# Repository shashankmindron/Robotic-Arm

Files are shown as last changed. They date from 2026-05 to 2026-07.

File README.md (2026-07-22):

# Robotic Arm — Mechanical Design → Embedded Firmware → ROS 2 Motion Planning







A self-designed 2-DOF five-bar linkage robotic arm, built as a full-stack robotics project: CAD → 3D-printed/machined hardware → custom embedded firmware → a ROS 2 + MoveIt 2 motion planning and control stack, connected over a hand-rolled binary serial protocol.

This isn't a simulation-only or tutorial-following project — every layer (mechanical, firmware, kinematics, planning, and the ros2_control integration) is custom-built for this specific arm's geometry and hardware.

## Highlights

- **Mechanical design:** Custom five-bar (parallel-linkage) arm designed in CAD from scratch — full STEP/STL source in [`cad/`](./cad)
- **Closed-form kinematics from first principles:** Derived and implemented forward and inverse kinematics for a five-bar linkage, including all 4 valid IK branches and transmission-angle singularity detection (`five_bar_kinematics.py`)
- **Motion planning:** An A* planner that searches over `(x, y, kinematic-branch)` states, costing branch switches and validating every candidate against MoveIt 2's live collision-checking service (`astar_planner.py`)
- **MoveIt 2 integration:** Full MoveIt Setup Assistant configuration (SRDF, kinematics, joint limits, RViz) driving real-time collision validation
- **`ros2_control` hardware plugin written in C++:** A `SystemInterface` plugin with a ring-buffer serial parser, custom packet framing, and lifecycle management (`arm_hardware_interface.cpp`)
- **Embedded firmware:** ESP32/Arduino firmware driving two closed-loop stepper drivers via `FastAccelStepper`, with fault/alarm handling and 50 Hz telemetry feedback
- **Designed a binary wire protocol** for low-latency, low-overhead host↔microcontroller communication (see [Serial Protocol](#serial-protocol))
- ~1,900 lines of original Python/C++/firmware code across planning, control, and embedded layers

## System Architecture

```
                     /target_pose (x, y)
                             │
                             ▼
                 ┌──────────────────────┐        /check_state_validity
                 │   robot_arm_ik       │◄───────────────────────────────┐
                 │   (ik_node.py)       │                                │
                 └─────────┬────────────┘                        ┌───────────────┐
                           │ plan request                        │    MoveIt 2   │
                           ▼                                     │  (collision   │
                 ┌──────────────────────┐                        │   checking)   │
                 │   A* Planner         │────────────────────────►               │
                 │ (branch + collision  │                        └───────────────┘
                 │  aware search)       │
                 └─────────┬────────────┘
                           │ synchronized motion frames (~100 Hz)
                           ▼
                 ┌─────────────────────┐   18-byte binary packets   ┌─────────────┐
                 │  Serial Link (UART  │───────────────────────────►│   ESP32     │
                 │  115200 baud        │◄───────────────────────────│  Firmware   │
                 └─────────────────────┘   11-byte telemetry (50Hz) └──────┬──────┘
                                                                           │
                                                                  FastAccelStepper
                                                                           │
                                                                 ┌─────────▼─────────┐
                                                                 │ 2× Stepper Motors │
                                                                 │ (T60 drivers)     │
                                                                 └───────────────────┘
```

## Repository Structure

```
Robotic-Arm/
├── cad/                          # Original CAD (STEP + STL) for the five-bar arm
├── firmware/esp_microros/        # ESP32 firmware — stepper control + binary serial protocol
├── src/
│   ├── arm_bringup/              # Top-level launch file for the full stack
│   ├── arm_commander/            # High-level command API (in progress)
│   ├── arm_hardware_interface/   # ros2_control C++ plugin + URDF/xacro + visual meshes
│   ├── arm_moveit_config/        # MoveIt 2 config (SRDF, kinematics, RViz, demo launch)
│   └── robot_arm_ik/             # Kinematics, planning, and the main control node
└── .gitignore
```

## How It Works

1. A target end-effector position is published on **`/target_pose`**.
2. The **A\* planner** searches the workspace, switching between the linkage's four kinematic branches when needed, validating each state live against MoveIt's collision service.
3. The resulting path is interpolated at ~100 Hz into per-tick motor angle/speed commands.
4. Commands are packed into compact binary frames and streamed to the ESP32 over serial.
5. The **firmware** drives both steppers via `FastAccelStepper`, monitors driver fault lines, and reports back live motor position at 50 Hz.
6. Live joint states are republished for RViz visualization and closed-loop tracking.

The same wire protocol is also exposed as a standard **`ros2_control`** hardware interface, so the arm can be driven through ROS 2's conventional controller pipeline (`position_controller` / `joint_state_broadcaster`) as well as the direct planning path.

## Tech Stack

| Layer | Tools |
|---|---|
| Mechanical | CAD (STEP/STL export) |
| Firmware | C++ (Arduino/ESP32), FastAccelStepper |
| Low-level control | C++, `ros2_control`, `pluginlib`, POSIX serial (termios) |
| Kinematics & Planning | Python, NumPy, custom A* search |
| Motion Planning Framework | ROS 2, MoveIt 2 |
| Communication | Custom binary serial protocol over UART |

## Serial Protocol

Designed for minimal latency and overhead between the host and the ESP32:

| Direction | Size | Layout |
|---|---|---|
| Host → ESP32 (command) | 18 bytes | `0xAA` \| `motor_a_rad` (f32) \| `motor_b_rad` (f32) \| `motor_a_hz` (f32) \| `motor_b_hz` (f32) \| `0xBB` |
| ESP32 → Host (telemetry) | 11 bytes | `0xCC` \| `status` (u8) \| `current_a_rad` (f32) \| `current_b_rad` (f32) \| `0xDD` |

## Getting Started

```bash
# 1. Build the ROS 2 workspace
colcon build
source install/setup.bash

# 2. Flash firmware/esp_microros/esp_microros.ino to the ESP32
#    (Arduino IDE or PlatformIO, with FastAccelStepper installed)

# 3. Launch the full stack
ros2 launch arm_bringup arm.launch.py

# 4. Send a target position
ros2 topic pub /target_pose geometry_msgs/msg/Point "{x: 0.0, y: 400.0}" --once

# 5. Visualize in RViz (optional)
ros2 launch arm_moveit_config demo.launch.py
```

## Roadmap

- [ ] High-level command API in `arm_commander`
- [ ] Trajectory blending for smoother multi-point paths
- [ ] Camera-based perception for closed-loop pick-and-place

## About Me

Built by **Shashank Vijavargia** — mechanical design, embedded firmware, and ROS 2 software all done end-to-end for this project.

*Add your LinkedIn / portfolio site / email here so recruiters can reach you.*

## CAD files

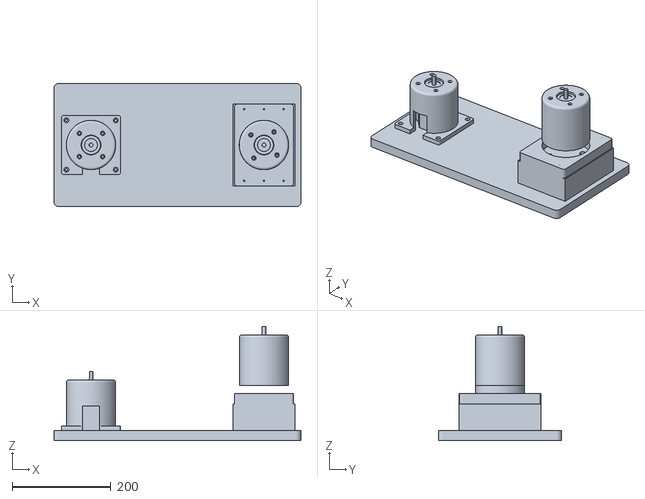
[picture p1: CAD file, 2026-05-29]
src/arm_hardware_interface/meshes/visual/base_assembly.stl
500.0 x 250.0 x 231.2

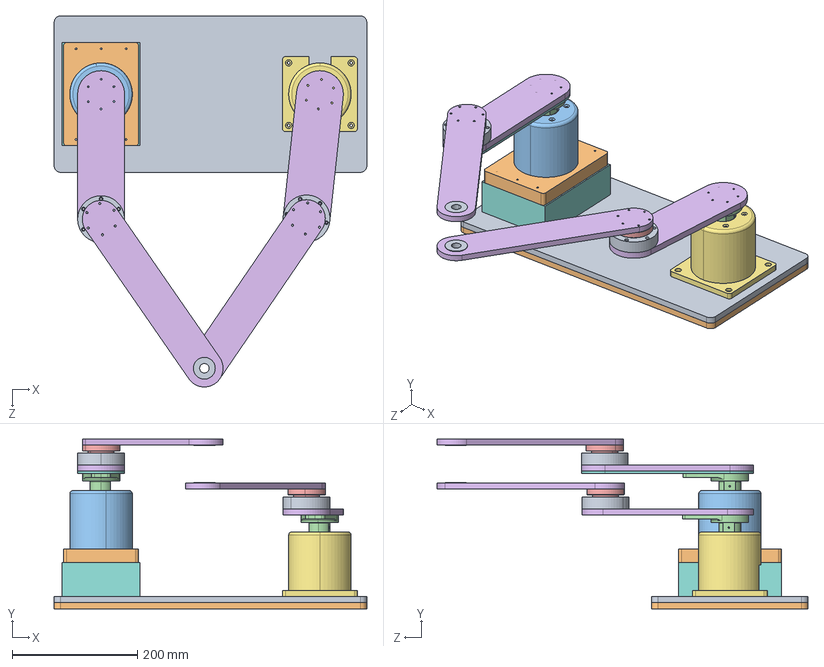
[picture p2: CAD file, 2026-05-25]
cad/scara arm.STEP
500.0 x 271.4 x 593.4 mm
base plate01
57am23ed1 x 2
FIRST MOTOR BASE SUPPORT
Linkage01 x 2
small 01 motor mounting plate
Base plate 02
bearing bush and support x 2
motor mounting base 01
motor mounting base 02
tappered roller bearing 32907 x 2
bush for 2nd bearing x 2
arm _2_1 x 2
Bearing small
Linkage01_01
35x15 bearing x 2

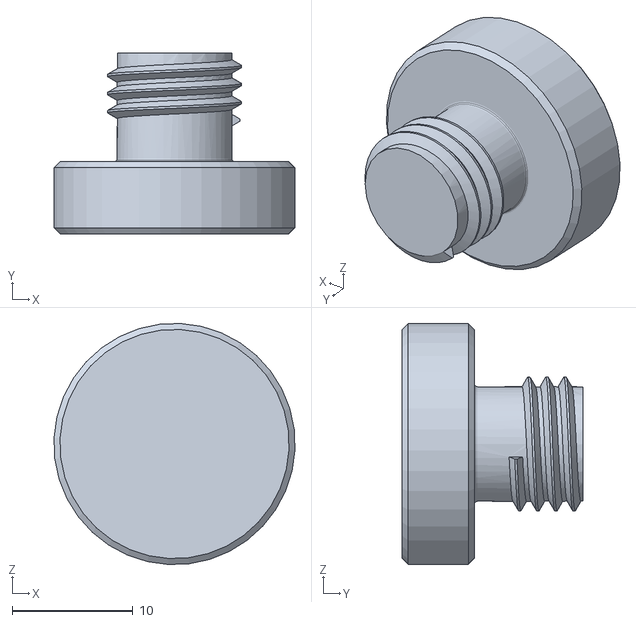
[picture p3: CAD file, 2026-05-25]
cad/stl/scara arm - threaded shaft bush-1.STL
20.0 x 15.0 x 20.0

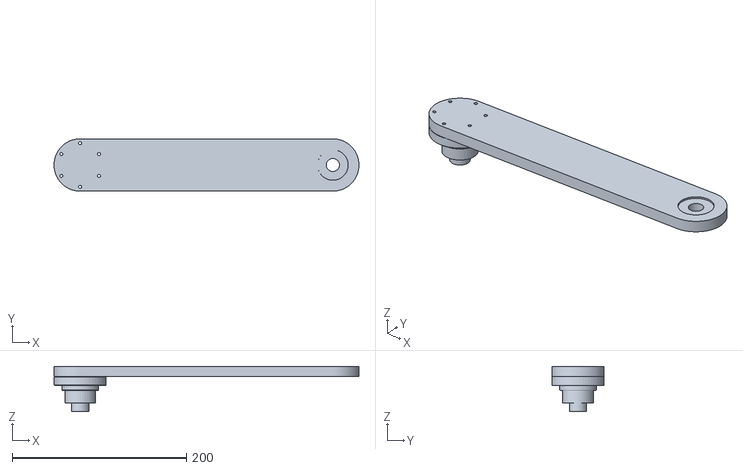
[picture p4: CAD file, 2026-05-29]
src/arm_hardware_interface/meshes/visual/distal_right.stl
350.0 x 60.0 x 51.7

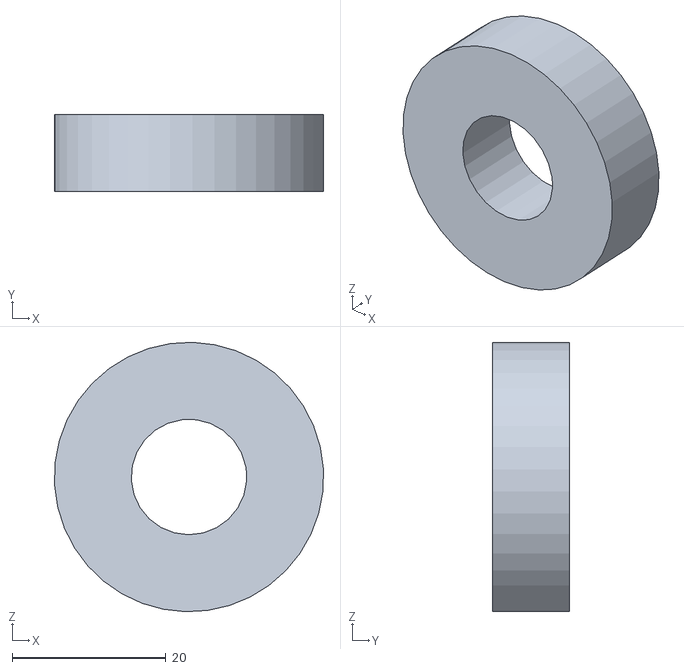
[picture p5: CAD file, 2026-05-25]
cad/stl/scara arm - 35x15 bearing-2.STL
34.9 x 10.0 x 35.0

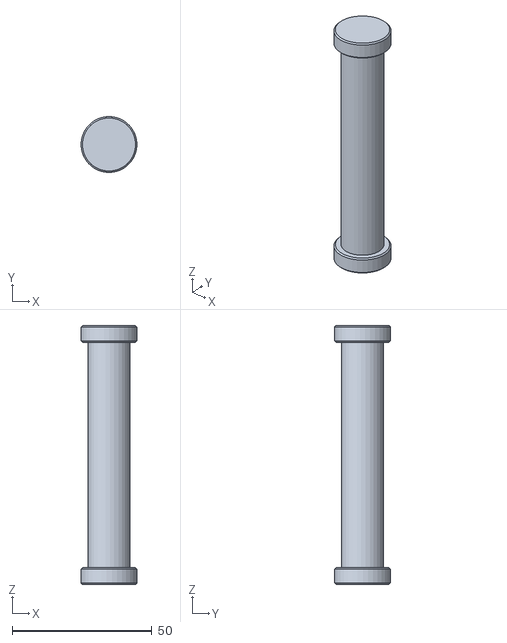
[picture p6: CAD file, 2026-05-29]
src/arm_hardware_interface/meshes/visual/end_effector.stl
20.0 x 20.0 x 92.6

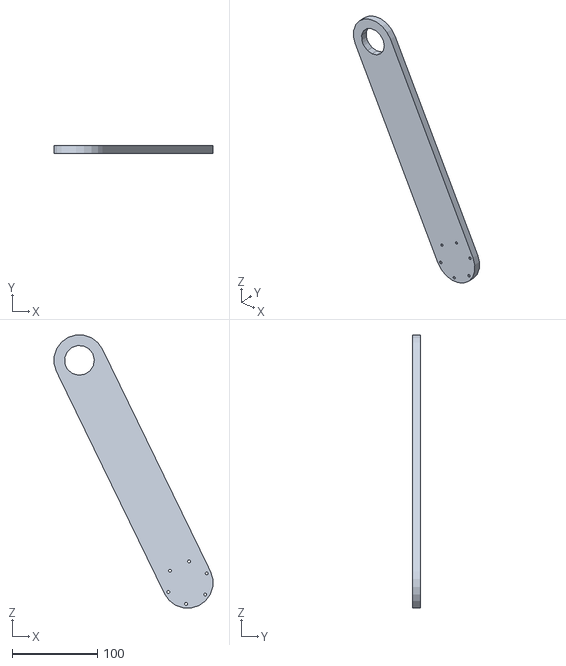
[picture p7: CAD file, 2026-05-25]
cad/stl/scara arm - arm _2_1-3.STL
186.3 x 9.20 x 320.2

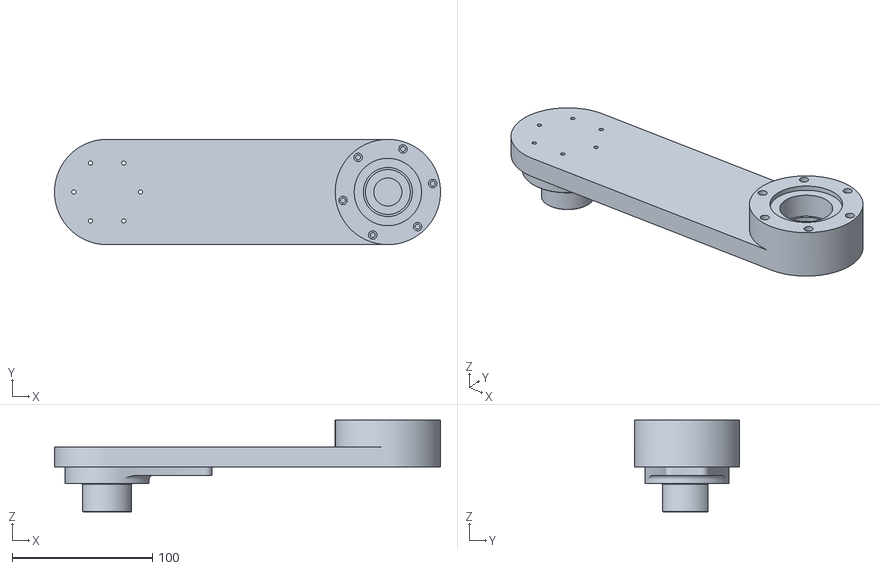
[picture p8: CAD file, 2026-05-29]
src/arm_hardware_interface/meshes/visual/proximal_left.stl
275.0 x 75.0 x 65.2

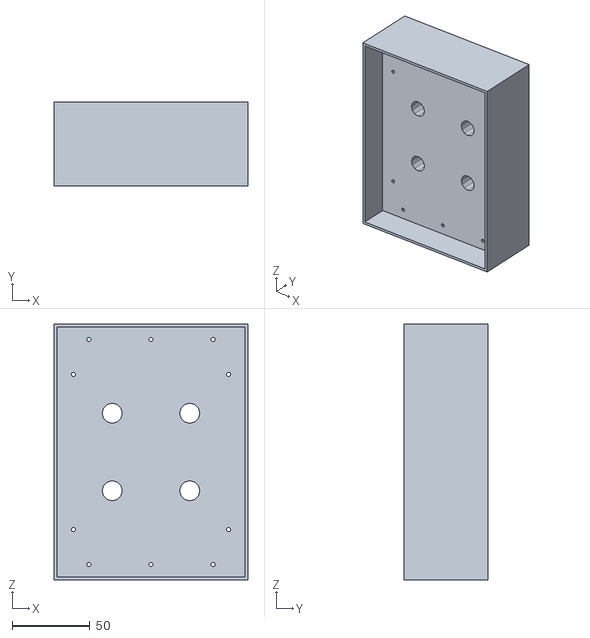
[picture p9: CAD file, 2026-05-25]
cad/stl/scara arm - Base plate 02-1.STL
125.0 x 54.0 x 165.0

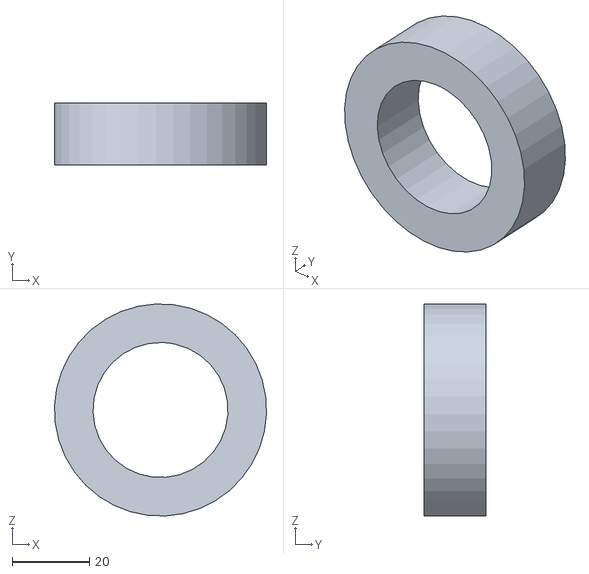
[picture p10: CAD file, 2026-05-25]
cad/stl/scara arm - tappered roller bearing 32907-1.STL
55.0 x 16.0 x 54.9

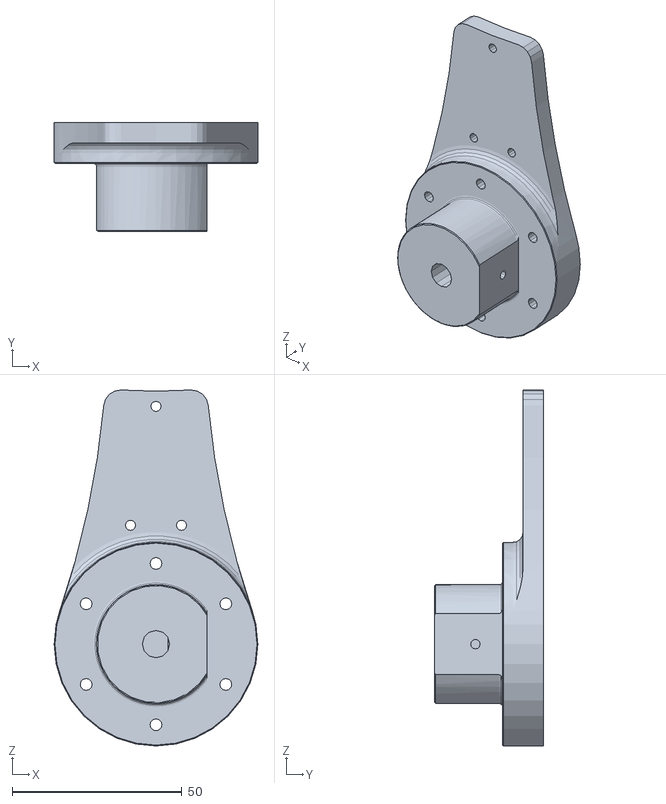
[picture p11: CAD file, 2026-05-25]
cad/stl/scara arm - 123-1.STL
60.0 x 32.0 x 104.8

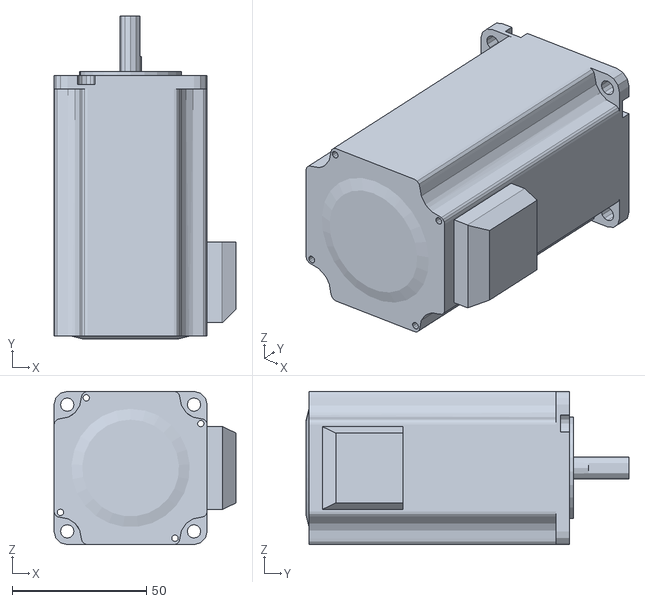
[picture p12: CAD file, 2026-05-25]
cad/stl/scara arm - 57am23ed1-2.STL
67.7 x 120.0 x 57.0

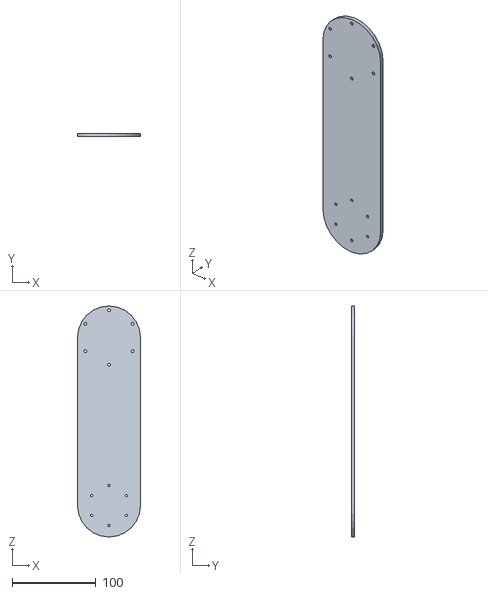
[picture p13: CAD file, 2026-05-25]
cad/stl/scara arm - Linkage01_01-1.STL
75.0 x 4.00 x 275.0

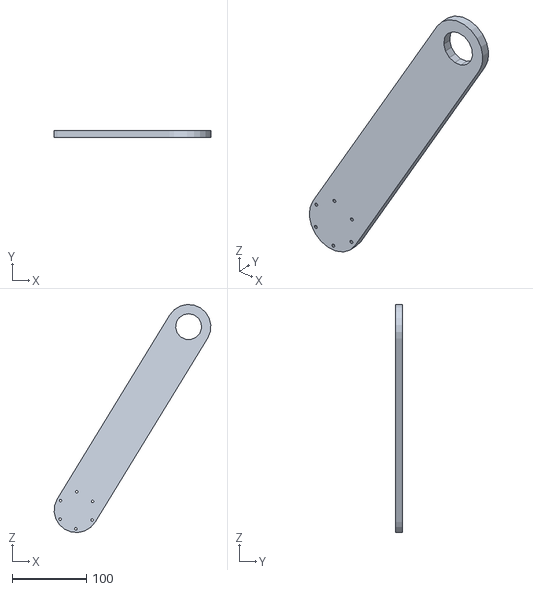
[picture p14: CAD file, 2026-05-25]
cad/stl/scara arm - arm _2_1-2.STL
211.1 x 9.20 x 307.2

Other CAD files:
cad/stl/scara arm - Linkage01-2.STL
cad/stl/scara arm - motor mounting base 02-2.STL
cad/stl/scara arm - 123-2.STL
cad/stl/scara arm - 35x15 bearing-1.STL
cad/stl/scara arm - 57am23ed1-1.STL
cad/stl/scara arm - Bearing small-3.STL
cad/stl/scara arm - FIRST MOTOR BASE SUPPORT-1.STL
cad/stl/scara arm - Linkage01-1.STL
cad/stl/scara arm - Part5-1.STL
cad/stl/scara arm - base plate01-1.STL
cad/stl/scara arm - bearing bush and support-1.STL
cad/stl/scara arm - bearing bush and support-2.STL
cad/stl/scara arm - bush for 2nd bearing-2.STL
cad/stl/scara arm - bush for 2nd bearing-3.STL
cad/stl/scara arm - motor mounting base 01-2.STL
cad/stl/scara arm - small 01 motor mounting plate-1.STL
cad/stl/scara arm - tappered roller bearing 32907-2.STL
cad/stl/scara arm - threaded shaft bush-2.STL

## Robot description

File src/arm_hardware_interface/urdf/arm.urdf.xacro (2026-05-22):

<?xml version="1.0"?>
<robot name="arm" xmlns:xacro="http://www.ros.org/wiki/xacro">
  <!-- Ground link -->
  <link name="base_link" />

  <!-- Motor joints (driven) -->
  <joint name="joint_a" type="revolute">
    <parent link="base_link"/>
    <child link="link_a"/>
    <origin xyz="0 0 0" rpy="0 0 0"/>
    <axis xyz="0 0 1"/>
    <limit lower="-3.14" upper="3.14" effort="1" velocity="1"/>
  </joint>

  <joint name="joint_b" type="revolute">
    <parent link="base_link"/>
    <child link="link_b"/>
    <origin xyz="0.1 0 0" rpy="0 0 0"/>  <!-- separation distance d -->
    <axis xyz="0 0 1"/>
    <limit lower="-3.14" upper="3.14" effort="1" velocity="1"/>
  </joint>

  <link name="link_a">
    <inertial>
      <mass value="0.1"/>
      <origin xyz="0 0 0"/>
      <inertia ixx="0.001" ixy="0" ixz="0" iyy="0.001" iyz="0" izz="0.001"/>
    </inertial>
  </link>
  <link name="link_b">
    <inertial>
      <mass value="0.1"/>
      <origin xyz="0 0 0"/>
      <inertia ixx="0.001" ixy="0" ixz="0" iyy="0.001" iyz="0" izz="0.001"/>
    </inertial>
  </link>

  <!-- Passive links (for completeness) -->

  <!-- ros2_control tag (keep your existing hardware plugin) -->
  <ros2_control name="ArmControl" type="system">
    <hardware>
      <plugin>arm_hardware_interface::ArmHardwareInterface</plugin>
      <param name="serial_port">/dev/ttyUSB0</param>
    </hardware>
    <joint name="joint_a">
      <command_interface name="position"/>
      <state_interface name="position"/>
    </joint>
    <joint name="joint_b">
      <command_interface name="position"/>
      <state_interface name="position"/>
    </joint>
  </ros2_control>
</robot>

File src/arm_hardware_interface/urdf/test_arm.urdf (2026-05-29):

<?xml version="1.0" ?>
<!-- =================================================================================== -->
<!-- |    This document was autogenerated by xacro from arm.urdf.xacro                 | -->
<!-- |    EDITING THIS FILE BY HAND IS NOT RECOMMENDED                                 | -->
<!-- =================================================================================== -->
<robot name="arm">
  <link name="base_link">
    <visual>
      <origin rpy="0 0 0" xyz="0 0 0"/>
      <geometry>
        <mesh filename="package://arm_hardware_interface/meshes/visual/base_assembly.stl" scale="0.001 0.001 0.001"/>
      </geometry>
      <material name="dark_grey">
        <color rgba="0.3 0.3 0.3 1.0"/>
      </material>
    </visual>
    <collision>
      <origin rpy="0 0 0" xyz="0 0 0"/>
      <geometry>
        <mesh filename="package://arm_hardware_interface/meshes/visual/base_assembly.stl" scale="0.001 0.001 0.001"/>
      </geometry>
    </collision>
    <inertial>
      <mass value="1.0"/>
      <origin xyz="0 0 0"/>
      <inertia ixx="0.01" ixy="0" ixz="0" iyy="0.01" iyz="0" izz="0.01"/>
    </inertial>
  </link>
  <joint name="joint_a" type="revolute">
    <parent link="base_link"/>
    <child link="link_a"/>
    <origin rpy="0 0 0" xyz="-0.175 0 0.12915"/>
    <axis xyz="0 0 1"/>
    <limit effort="10.0" lower="-3.14" upper="3.14" velocity="3.0"/>
  </joint>
  <link name="link_a">
    <visual>
      <origin rpy="0 0 0" xyz="0 0 0"/>
      <geometry>
        <mesh filename="package://arm_hardware_interface/meshes/visual/proximal_left.stl" scale="0.001 0.001 0.001"/>
      </geometry>
      <material name="orange">
        <color rgba="0.9 0.45 0.0 1.0"/>
      </material>
    </visual>
    <collision>
      <origin rpy="0 0 0" xyz="0 0 0"/>
      <geometry>
        <mesh filename="package://arm_hardware_interface/meshes/visual/proximal_left.stl" scale="0.001 0.001 0.001"/>
      </geometry>
    </collision>
    <inertial>
      <mass value="0.1"/>
      <origin xyz="0.100 0 0"/>
      <inertia ixx="0.001" ixy="0" ixz="0" iyy="0.001" iyz="0" izz="0.001"/>
    </inertial>
  </link>
  <joint name="joint_b" type="revolute">
    <parent link="base_link"/>
    <child link="link_b"/>
    <origin rpy="0 0 0" xyz="0.175 0 0.22035"/>
    <axis xyz="0 0 1"/>
    <limit effort="10.0" lower="-3.14" upper="3.14" velocity="3.0"/>
  </joint>
  <link name="link_b">
    <visual>
      <origin rpy="0 0 0" xyz="0 0 0"/>
      <geometry>
        <mesh filename="package://arm_hardware_interface/meshes/visual/proximal_right.stl" scale="0.001 0.001 0.001"/>
      </geometry>
      <material name="orange"/>
    </visual>
    <collision>
      <origin rpy="0 0 0" xyz="0 0 0"/>
      <geometry>
        <mesh filename="package://arm_hardware_interface/meshes/visual/proximal_right.stl" scale="0.001 0.001 0.001"/>
      </geometry>
    </collision>
    <inertial>
      <mass value="0.1"/>
      <origin xyz="0.100 0 0"/>
      <inertia ixx="0.001" ixy="0" ixz="0" iyy="0.001" iyz="0" izz="0.001"/>
    </inertial>
  </link>
  <joint name="joint_distal_a" type="continuous">
    <parent link="link_a"/>
    <child link="link_distal_a"/>
    <origin rpy="0 0 0" xyz="0.200 0 0.044"/>
    <axis xyz="0 0 1"/>
  </joint>
  <link name="link_distal_a">
    <visual>
      <origin rpy="0 0 0" xyz="0 0 0"/>
      <geometry>
        <mesh filename="package://arm_hardware_interface/meshes/visual/distal_left.stl" scale="0.001 0.001 0.001"/>
      </geometry>
      <material name="blue">
        <color rgba="0.1 0.4 0.8 1.0"/>
      </material>
    </visual>
    <collision>
      <origin rpy="0 0 0" xyz="0 0 0"/>
      <geometry>
        <mesh filename="package://arm_hardware_interface/meshes/visual/distal_left.stl" scale="0.001 0.001 0.001"/>
      </geometry>
    </collision>
    <inertial>
      <mass value="0.1"/>
      <origin xyz="0.1446 0 0"/>
      <inertia ixx="0.001" ixy="0" ixz="0" iyy="0.001" iyz="0" izz="0.001"/>
    </inertial>
  </link>
  <joint name="joint_distal_b" type="continuous">
    <parent link="link_b"/>
    <child link="link_distal_b"/>
    <origin rpy="0 0 0" xyz="0.200 0 0.044"/>
    <axis xyz="0 0 1"/>
  </joint>
  <link name="link_distal_b">
    <visual>
      <origin rpy="0 0 0" xyz="0 0 0"/>
      <geometry>
        <mesh filename="package://arm_hardware_interface/meshes/visual/distal_right.stl" scale="0.001 0.001 0.001"/>
      </geometry>
      <material name="blue"/>
    </visual>
    <collision>
      <origin rpy="0 0 0" xyz="0 0 0"/>
      <geometry>
        <mesh filename="package://arm_hardware_interface/meshes/visual/distal_right.stl" scale="0.001 0.001 0.001"/>
      </geometry>
    </collision>
    <inertial>
      <mass value="0.1"/>
      <origin xyz="0.1446 0 0"/>
      <inertia ixx="0.001" ixy="0" ixz="0" iyy="0.001" iyz="0" izz="0.001"/>
    </inertial>
  </link>
  <joint name="joint_ee" type="continuous">
    <parent link="link_distal_a"/>
    <child link="end_effector"/>
    <origin rpy="0 0 0" xyz="0.290 0 0.022"/>
    <axis xyz="0 0 1"/>
  </joint>
  <link name="end_effector">
    <visual>
      <origin rpy="0 0 0" xyz="0 0 0"/>
      <geometry>
        <mesh filename="package://arm_hardware_interface/meshes/visual/end_effector.stl" scale="0.001 0.001 0.001"/>
      </geometry>
      <material name="red">
        <color rgba="0.9 0.1 0.1 1.0"/>
      </material>
    </visual>
    <collision>
      <origin rpy="0 0 0" xyz="0 0 0"/>
      <geometry>
        <mesh filename="package://arm_hardware_interface/meshes/visual/end_effector.stl" scale="0.001 0.001 0.001"/>
      </geometry>
    </collision>
    <inertial>
      <mass value="0.05"/>
      <origin xyz="0 0 0"/>
      <inertia ixx="0.0001" ixy="0" ixz="0" iyy="0.0001" iyz="0" izz="0.0001"/>
    </inertial>
  </link>
  <ros2_control name="ArmControl" type="system">
    <hardware>
      <!--<plugin>arm_hardware_interface::ArmHardwareInterface</plugin>
      <param name="serial_port">/dev/ttyUSB0</param>-->
      <plugin>mock_components/GenericSystem</plugin>
    </hardware>
    <joint name="joint_a">
      <command_interface name="position"/>
      <state_interface name="position"/>
    </joint>
    <joint name="joint_b">
      <command_interface name="position"/>
      <state_interface name="position"/>
    </joint>
  </ros2_control>
</robot>

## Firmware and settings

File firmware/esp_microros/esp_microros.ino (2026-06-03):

#include <Arduino.h>
#include <FastAccelStepper.h>

// ==========================================
// PIN DEFINITIONS (T60 Drivers)
// ==========================================
const int PUL_A = 13;
const int DIR_A = 14;
const int ENA_A = 27;
const int ALM_A = 25;

const int PUL_B = 4;
const int DIR_B = 16;
const int ENA_B = 18;
const int ALM_B = 26;

// ==========================================
// SYSTEM OBJECTS
// ==========================================
FastAccelStepperEngine engine = FastAccelStepperEngine();
FastAccelStepper *stepperA = NULL;
FastAccelStepper *stepperB = NULL;

// Protocol Constraints
const uint8_t RX_HEADER = 0xAA;
const uint8_t RX_FOOTER = 0xBB;
const int RX_PACKET_SIZE = 18;

const uint8_t TX_HEADER = 0xCC;
const uint8_t TX_FOOTER = 0xDD;

uint8_t rx_buffer[RX_PACKET_SIZE];
int rx_index = 0;

// Struct for Jetson -> ESP32 (Commands)
#pragma pack(push, 1)
struct ArmCommand {
  uint8_t start_byte;
  float motor_a_rad;
  float motor_b_rad;
  float motor_a_hz;
  float motor_b_hz;
  uint8_t end_byte;
};
#pragma pack(pop)

// Struct for ESP32 -> Jetson (Feedback)
#pragma pack(push, 1)
struct ArmFeedback {
  uint8_t start_byte;
  uint8_t status_code; // 0 = Normal, 1 = Hardware Alarm
  float current_a_rad;
  float current_b_rad;
  uint8_t end_byte;
};
#pragma pack(pop)

ArmFeedback telemetry;

// Alarm Tracking
unsigned long alarm_trigger_time = 0;
bool is_in_alarm_state = false;
const uint8_t ALARM_ACTIVE_STATE = HIGH; // Change to HIGH if T60 uses NO logic

// Telemetry Timing
unsigned long last_telemetry_time = 0;

void setupSteppers() {
    engine.init();

    stepperA = engine.stepperConnectToPin(PUL_A);
    if (stepperA) {
        stepperA->setDirectionPin(DIR_A);
        stepperA->setEnablePin(ENA_A);
        stepperA->setAutoEnable(false); 
        stepperA->enableOutputs();
        stepperA->setAcceleration(20000); 
    }

    stepperB = engine.stepperConnectToPin(PUL_B);
    if (stepperB) {
        stepperB->setDirectionPin(DIR_B);
        stepperB->setEnablePin(ENA_B);
        stepperB->setAutoEnable(false);
        stepperB->enableOutputs();
        stepperB->setAcceleration(20000); 
    }
}

void processValidPacket(uint8_t* buffer) {
    float angleA, angleB, speedA, speedB;

    memcpy(&angleA, &buffer[1], 4);
    memcpy(&angleB, &buffer[5], 4);
    memcpy(&speedA, &buffer[9], 4);
    memcpy(&speedB, &buffer[13], 4);

    const float radToPulse = 3200.0f / TWO_PI;
    int32_t targetPulsesA = round(angleA * radToPulse);
    int32_t targetPulsesB = round(angleB * radToPulse);

    uint32_t speedHzA = (uint32_t)abs(speedA);
    uint32_t speedHzB = (uint32_t)abs(speedB);

    if (speedHzA > 0) stepperA->setSpeedInHz(speedHzA);
    if (speedHzB > 0) stepperB->setSpeedInHz(speedHzB);

    stepperA->moveTo(targetPulsesA);
    stepperB->moveTo(targetPulsesB);
}

void setup() {
    Serial.begin(115200);
    
    pinMode(ALM_A, INPUT_PULLUP);
    pinMode(ALM_B, INPUT_PULLUP);

    setupSteppers();
}

void loop() {
    // 1. RECEIVE COMMANDS
    if (!is_in_alarm_state) {
        while (Serial.available() > 0) {
            uint8_t incomingByte = Serial.read();

            if (rx_index == 0) {
                if (incomingByte == RX_HEADER) rx_buffer[rx_index++] = incomingByte;
            } else {
                rx_buffer[rx_index++] = incomingByte;
                if (rx_index == RX_PACKET_SIZE) {
                    if (rx_buffer[RX_PACKET_SIZE - 1] == RX_FOOTER) {
                        processValidPacket(rx_buffer); 
                    } else {
                        while(Serial.available()) Serial.read(); 
                    }
                    rx_index = 0; 
                }
            }
        }
    }

    // 2. T60 ALARM CHECK (50ms Anti-Noise Debounce)
    bool a_fault = false;//(digitalRead(ALM_A) == ALARM_ACTIVE_STATE);
    bool b_fault = false;//(digitalRead(ALM_B) == ALARM_ACTIVE_STATE);

    if (a_fault || b_fault) {
        if (alarm_trigger_time == 0) alarm_trigger_time = millis(); 
        else if (millis() - alarm_trigger_time > 50) { 
            if (!is_in_alarm_state) {
                stepperA->stopMove();
                stepperB->stopMove();
                is_in_alarm_state = true;
            }
        }
    } else {
        alarm_trigger_time = 0; 
    }

    // 3. TRANSMIT TELEMETRY (Every 20ms = 50Hz)
    if (millis() - last_telemetry_time >= 20) {
        last_telemetry_time = millis();

        telemetry.start_byte = TX_HEADER;
        telemetry.status_code = is_in_alarm_state ? 1 : 0;
        
        // Convert physical pulses back into Radians
        const float pulseToRad = TWO_PI / 3200.0f;
        telemetry.current_a_rad = stepperA->getCurrentPosition() * pulseToRad;
        telemetry.current_b_rad = stepperB->getCurrentPosition() * pulseToRad;
        
        telemetry.end_byte = TX_FOOTER;

        // Blast 11-byte binary packet directly down the USB cable
        Serial.write((uint8_t*)&telemetry, sizeof(ArmFeedback));
    }
}


// // Define the pin connection
// const int dataPin = 15; // GPIO 15 corresponds to D15 on most ESP32 boards
// int sensorValue = 0;    // Variable to store the data

// void setup() {
//   // Initialize serial communication at 115200 baud (standard for ESP32)
//   Serial.begin(250000);
  
//   // Configure the data pin as an input
//   pinMode(dataPin, INPUT);
// }

// void loop() {
//   // Read the state of the pin (HIGH or LOW / 1 or 0)
//   sensorValue = digitalRead(dataPin);
  
//   // Print the value to the Serial Monitor
//   Serial.print("Data from D15: ");
//   Serial.println(sensorValue);
  
//   // Wait for half a second before reading again to avoid flooding the monitor
//   delay(500); 
// }

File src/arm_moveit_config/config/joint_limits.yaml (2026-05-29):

# joint_limits.yaml allows the dynamics properties specified in the URDF to be overwritten or augmented as needed

# For beginners, we downscale velocity and acceleration limits.
# You can always specify higher scaling factors (<= 1.0) in your motion requests.  # Increase the values below to 1.0 to always move at maximum speed.
default_velocity_scaling_factor: 0.1
default_acceleration_scaling_factor: 0.1

# Specific joint properties can be changed with the keys [max_position, min_position, max_velocity, max_acceleration]
# Joint limits can be turned off with [has_velocity_limits, has_acceleration_limits]
joint_limits:
  joint_a:
    has_velocity_limits: true
    max_velocity: 3.0
    has_acceleration_limits: false
    max_acceleration: 0.0
  joint_b:
    has_velocity_limits: true
    max_velocity: 3.0
    has_acceleration_limits: false
    max_acceleration: 0.0

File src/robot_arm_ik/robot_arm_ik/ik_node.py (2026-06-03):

#!/usr/bin/env python3
import rclpy
from rclpy.node import Node
from rclpy.callback_groups import MutuallyExclusiveCallbackGroup
from rclpy.executors import MultiThreadedExecutor

import numpy as np
import math
import struct
import time
import serial
import threading

from geometry_msgs.msg import Point
from std_msgs.msg import Float64MultiArray
from sensor_msgs.msg import JointState
from moveit_msgs.msg import DisplayRobotState

# Import your custom mathematical brains
from robot_arm_ik.five_bar_kinematics import FiveBarKinematics
from robot_arm_ik.astar_planner import AStarPlanner

class RobotArmIKNode(Node):
    def __init__(self, planner_node):
        super().__init__('robot_arm_ik')

        self.sub_cb_group = MutuallyExclusiveCallbackGroup()
        self.timer_cb_group = MutuallyExclusiveCallbackGroup()
        self.telemetry_cb_group = MutuallyExclusiveCallbackGroup()

        self.declare_parameter('serial_port', '/dev/ttyUSB0')
        self.declare_parameter('baud_rate', 115200)
        port = self.get_parameter('serial_port').get_parameter_value().string_value
        baud = self.get_parameter('baud_rate').get_parameter_value().integer_value
        
        try:
            self.esp32 = serial.Serial(port, baud, timeout=1)
            self.get_logger().info(f"Connected to ESP32 on {port} at {baud} baud.")
        except Exception as e:
            self.get_logger().warn(f"Failed to open UART: {e}. Running in Simulation-Only mode!")
            self.esp32 = None

        self.hardware_alarm = False
        self.live_rad_a = math.pi / 2.0  
        self.live_rad_b = math.pi / 2.0
        self.is_running = True
        
        if self.esp32 is not None:
            self.listener_thread = threading.Thread(target=self.serial_listener, daemon=True)
            self.listener_thread.start()

        self.kinematics = FiveBarKinematics()
        self.planner = planner_node 

        self.current_x = 0.0
        self.current_y = 431.25 
        self.current_geo_angles = None
        self.current_branch = None 
        
        home_solutions = self.kinematics.ik_5bar(self.current_x, self.current_y)
        if home_solutions:
            for name, angles in home_solutions.items():
                if math.isclose(angles[0], math.pi/2.0, abs_tol=0.1) and math.isclose(angles[1], math.pi/2.0, abs_tol=0.1):
                    self.current_geo_angles = angles
                    self.current_branch = name
                    break
        
        if self.current_geo_angles is None:
            self.current_geo_angles = (math.pi / 2.0, math.pi / 2.0, -0.6478, 0.6478)
            self.current_branch = 'out_out'

        # =========================================================================
        # THE FIX: CONTINUOUS MOTOR TRACKERS
        # This isolates the physical motors from the mathematical Wrap-Around bug!
        # =========================================================================
        self.continuous_motor_a = self.current_geo_angles[0] - (math.pi / 2.0)
        self.continuous_motor_b = self.current_geo_angles[1] - (math.pi / 2.0)

        self.execution_queue = []
        self.exec_timer = self.create_timer(0.01, self.execution_timer_callback, callback_group=self.timer_cb_group)
        self.telemetry_timer = self.create_timer(0.02, self.broadcast_telemetry_callback, callback_group=self.telemetry_cb_group)

        self.declare_parameter('command_topic', '/position_controller/commands')
        command_topic = self.get_parameter('command_topic').get_parameter_value().string_value

        self.pose_sub = self.create_subscription(Point, '/target_pose', self.pose_callback, 10, callback_group=self.sub_cb_group)
        self.joint_pub = self.create_publisher(Float64MultiArray, command_topic, 10)
        self.display_pub = self.create_publisher(DisplayRobotState, '/display_robot_state', 10)
        self.live_joint_pub = self.create_publisher(JointState, '/live_joint_states', 10)

        self.get_logger().info(f"Autonomous Nervous System Online. Layer: '{self.current_branch}'")
        self.is_idle = True 
        self.startup_timer = self.create_timer(2.0, self.spawn_initial_robot, callback_group=self.sub_cb_group)

    def serial_listener(self):
        while self.is_running:
            try:
                if self.esp32.in_waiting >= 11:
                    byte = self.esp32.read(1)
                    if byte == b'\xCC':
                        payload = self.esp32.read(10)
                        if payload[-1] == 0xDD:
                            status, raw_rad_a, raw_rad_b = struct.unpack('<Bff', payload[:9])
                            self.live_rad_a = raw_rad_a + (math.pi / 2.0)
                            self.live_rad_b = raw_rad_b + (math.pi / 2.0)
                            
                            if status == 1 and not self.hardware_alarm:
                                self.hardware_alarm = True
                                self.get_logger().fatal("HARDWARE ALARM DETECTED! Clearing queue.")
                                self.execution_queue.clear()
            except Exception:
                break

    def broadcast_telemetry_callback(self):
        msg = JointState()
        msg.header.stamp = self.get_clock().now().to_msg()
        msg.name = ['joint_a', 'joint_b']
        msg.position = [float(self.live_rad_a), float(self.live_rad_b)]
        self.live_joint_pub.publish(msg)

    def destroy_node(self):
        self.is_running = False
        if self.esp32 is not None:
            time.sleep(0.1)
            self.esp32.close()
        super().destroy_node()

    def publish_rviz(self, geo_angles):
        drs = DisplayRobotState()
        js = JointState()
        js.name = ['joint_a', 'joint_b', 'joint_distal_a', 'joint_distal_b']
        js.position = [float(geo_angles[0]), float(geo_angles[1]), float(geo_angles[2]), float(geo_angles[3])]
        drs.state.joint_state = js
        self.display_pub.publish(drs)

    def spawn_initial_robot(self):
        if not self.is_idle:
            self.startup_timer.cancel()
            return
        self.publish_rviz(self.current_geo_angles)

    def execution_timer_callback(self):
        if self.hardware_alarm or not self.execution_queue:
            return

        cmd = self.execution_queue.pop(0)
        
        if self.esp32 is not None:
            packet = struct.pack('<BffffB', 0xAA, cmd['motor_a'], cmd['motor_b'], cmd['hz_a'], cmd['hz_b'], 0xBB)
            self.esp32.write(packet)
            
        msg_out = Float64MultiArray()
        msg_out.data = [float(cmd['motor_a']), float(cmd['motor_b'])]
        self.joint_pub.publish(msg_out)
        self.publish_rviz(cmd['geo_angles'])
        
        if not self.execution_queue:
            self.get_logger().info("--- Route Complete! Constant Velocity Maintained. ---")
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

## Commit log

2026-05-22 Initial commit of ROS 2 workspace src
    [arm.urdf.xacro, ros2_controllers.yaml]
2026-05-22 Add ESP32 firmware
2026-05-22 Fix launch, URDF, hardware interface; add ESP32 firmware
    [arm.urdf.xacro, ros2_controllers.yaml]
2026-05-25 Add CAD and mesh files, update CMakeLists
    [base_plate_01.stl, base_plate_02.stl, bearing_35x15_1.stl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]
2026-05-29 Add CAD, meshes, update CMakeLists and firmware changes
    [base_assembly.stl, base_plate_01.stl, base_plate_02.stl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]
